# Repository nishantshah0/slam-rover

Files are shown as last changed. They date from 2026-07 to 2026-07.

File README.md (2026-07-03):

# SLAM Rover — Open-Source Design Package

A complete, buildable design for a budget (~$400 CAD) SLAM-capable autonomous rover: 3D-printed chassis CAD, simulation-tested Pico W firmware, wiring plans, risk analysis, and a staged bill of materials. Published as a reference design — everything needed to build one lives in this repo.

**What's here and how far it's been validated:**
- **Firmware** (MicroPython, Pico W): motor control, PIO quadrature encoders, WiFi/USB command protocol with fail-safe watchdog — validated 9/9 in a [host-side simulation harness](pico/host_test/run_sim.py)
- **CAD**: parametric chassis system — plate, motor clamps, and tolerance test coupon (Onshape); wheels, caster spacer, and body shell (OpenSCAD, sources included) — structural parts printed and dry-fitted on a Bambu P1S
- **Engineering docs**: [decision log](docs/decisions.md) (D1–D9), [risk register](docs/risks.md) (R1–R10), [staged BOM](docs/shopping-list.md), [build roadmap](docs/roadmap.md), [debugging log](docs/debugging-log.md)
- Hardware bring-up (motors/lidar/SLAM on the physical robot) is designed and documented but not yet executed — the [phase 1 guide](docs/phase1-guide.md) is the runbook for whoever does it first

## Gallery

| | | |
|---|---|---|
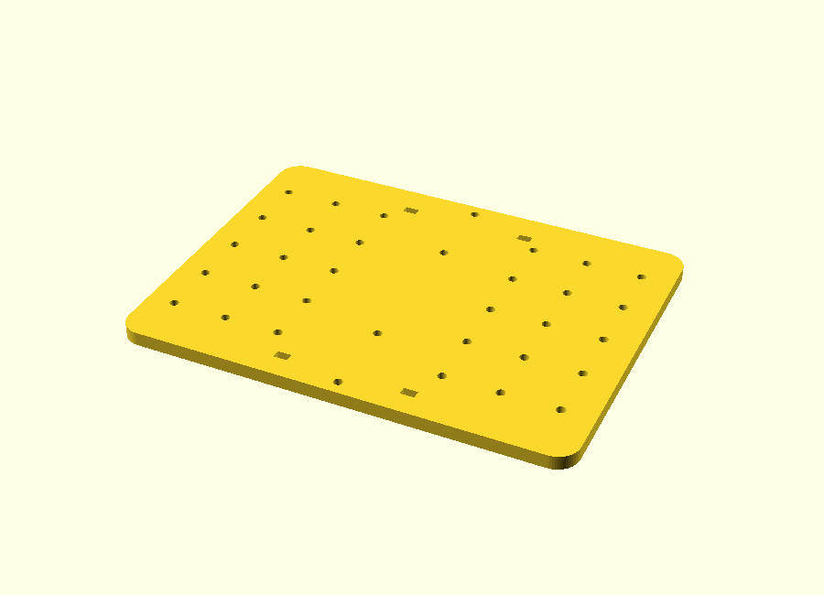
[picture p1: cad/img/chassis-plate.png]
chassis plate
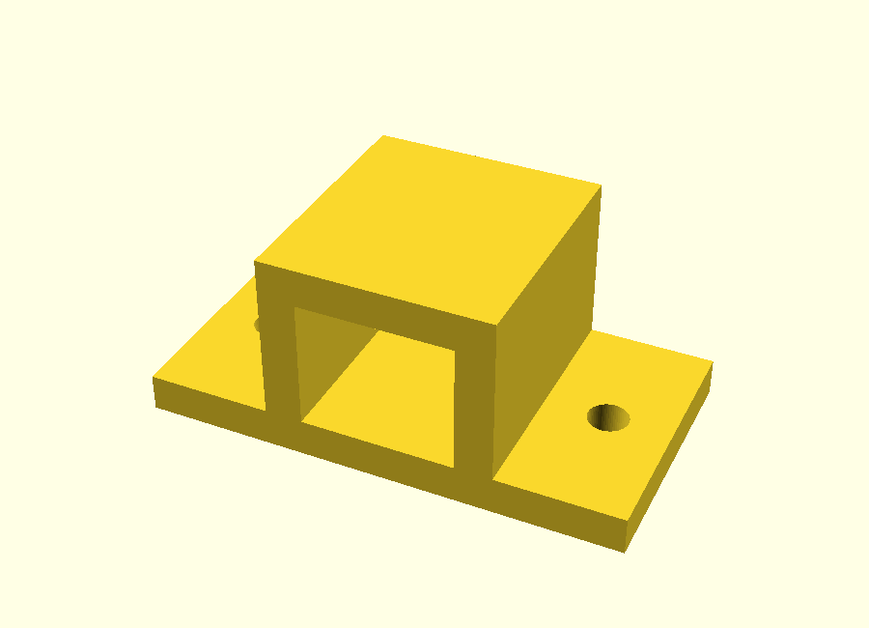
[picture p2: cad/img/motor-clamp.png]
motor clamp
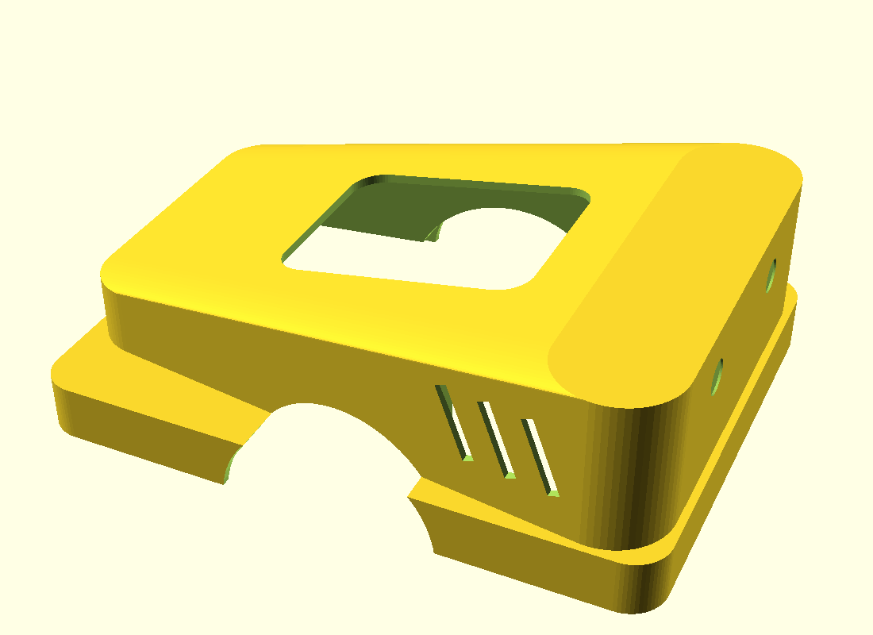
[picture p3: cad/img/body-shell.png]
body shell
|  |  |  |
| Chassis plate (34-hole grid system) | Motor clamp (N20, no-fastener tunnel) | Body shell (printable car-body skin) |
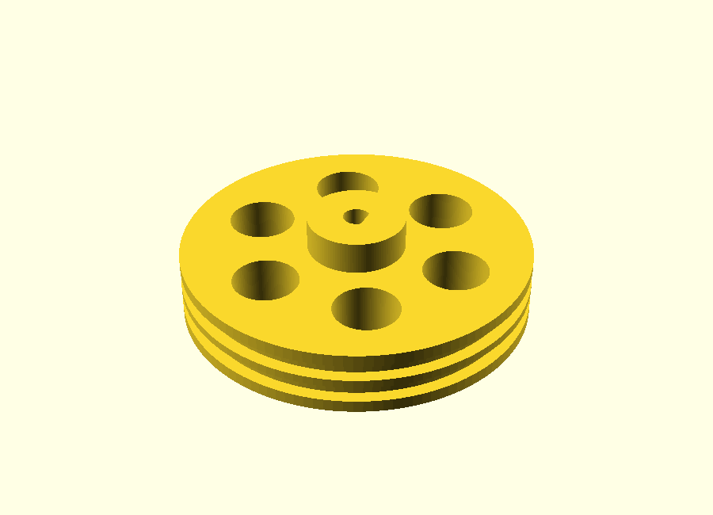
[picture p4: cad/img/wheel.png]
wheel
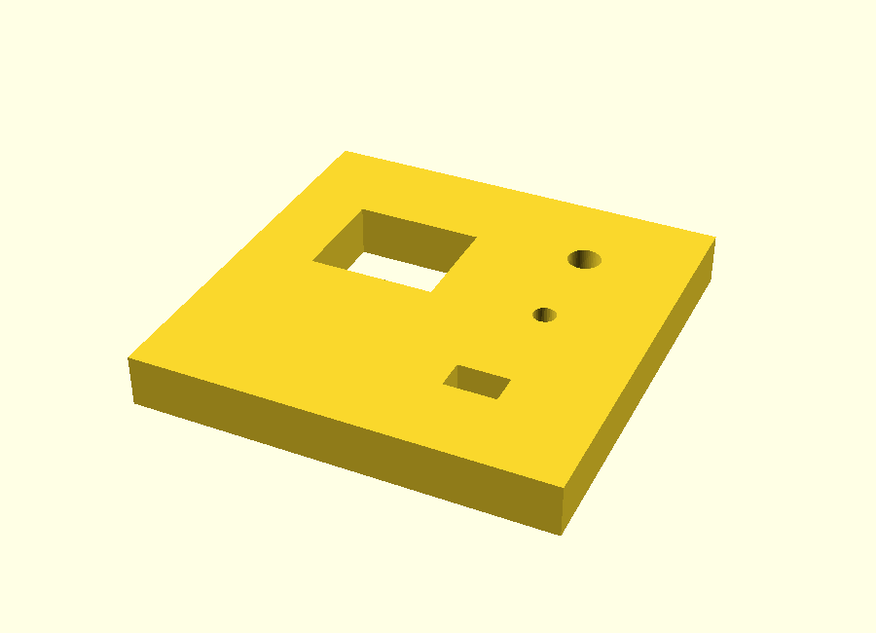
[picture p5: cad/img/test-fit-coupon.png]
test coupon
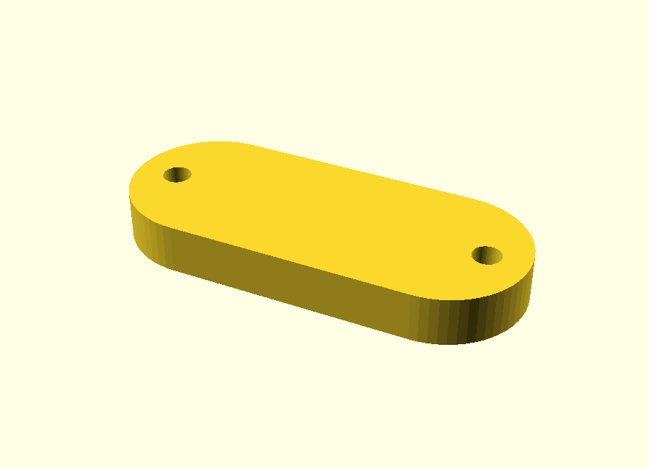
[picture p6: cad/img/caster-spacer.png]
caster spacer
|  |  |  |
| Drive wheel (rubber-band tires, D-bore) | Tolerance test coupon | Parametric caster spacer |

## Hardware

| Component | Choice | Rationale | Status |
|---|---|---|---|
| Compute | Raspberry Pi 5 | Runs ROS2 + SLAM | Decided |
| Real-time motor control | Raspberry Pi Pico | PWM + **encoder counting** (PIO) | Decided |
| Sensing | RPLidar A1 | Direct `LaserScan` fit for slam_toolbox ([D2](docs/decisions.md)) | Proposed |
| Chassis | **3D-printed diff-drive plate + caster** (Bambu P1S) | Skid-steer corrupts odometry; printing saves $ and adds CAD to portfolio ([D5](docs/decisions.md)) | Proposed |
| Motors | **N20 gearmotors with quadrature encoders** | SLAM needs odometry — encoders are not optional ([R1](docs/risks.md)) | Proposed |
| Motor driver | TB6612FNG or Cytron MDD3A (**not L298N**) | L298N wastes 2–4 V as heat ([D6](docs/decisions.md)) | Proposed |
| Power | Battery → motor rail + separate 5V/5A buck → Pi | Shared rail = brownout reboots ([D7](docs/decisions.md)) | Proposed |

3D printing (Bambu P1S) covers all *structure*: chassis plate, motor mounts, wheel hubs, lidar mast, Pi/Pico tray. Drivetrain internals (motors, gears, caster) stay off-the-shelf. Budget: **~$340–425 CAD total, bought in three stages of ~$90–165** ([shopping-list.md](docs/shopping-list.md)).

## Software Stack

- **ROS2 Jazzy** on Ubuntu 24.04 — *not Humble*: Humble's Ubuntu 22.04 doesn't support the Pi 5 ([D1](docs/decisions.md))
- **slam_toolbox** for SLAM
- **Nav2** for autonomous navigation (stretch goal)
- **Python** for ROS2 nodes; **MicroPython + PIO** on the Pico ([D4](docs/decisions.md))
- Dev environment: WSL2 (learning) + headless Pi + Foxglove Studio (live viz) ([D8](docs/decisions.md))

## Phased Build Plan (~6–8 weeks)

### Phase 0 (Week 0) — Order parts & set up dev environment
Shipping eats calendar time — order **Stage 1** of the [shopping list](docs/shopping-list.md) now (later stages get bought as earlier ones succeed). Meanwhile, all $0: WSL2 + Ubuntu 24.04 + ROS2 Jazzy on the Windows machine; chassis CAD in Onshape; firmware drafted in the Wokwi simulator; GitHub repo created ([D9](docs/decisions.md)). The Pi gets flashed when the Stage 2 box arrives (~week 2).

### Phase 1 (Weeks 1–2) — Get it moving
Assemble chassis, wire motor driver + Pico + two-rail power. Pico firmware: PWM drive, **encoder counting via PIO**, serial protocol, **command watchdog (fail-safe stop, [R4](docs/risks.md))**. Keyboard teleop over SSH. **No ROS2 yet** — isolate hardware learning from software learning.

### Phase 2 (Weeks 3–4) — ROS2 fundamentals + sensing + odometry
Two parallel tracks:
- **Learning track (WSL2, no robot):** nodes, topics, pub/sub, launch files, tf basics.
- **Robot track (Pi):** lidar publishing `LaserScan`; serial-bridge node (`cmd_vel` → Pico, encoder counts → Pi); **odometry node** publishing `odom` + the `odom → base_link` transform. Doing odometry here keeps Phase 3 from overloading.

### Phase 3 (Weeks 5–6) — SLAM integration
slam_toolbox + tf tree (`map → odom → base_link → laser`). Debug coordinate frames, lidar mounting/orientation ([R8](docs/risks.md)), drift; tune. Drive the room, save a clean map.

**✅ Success checkpoint: a rover that maps a room cleanly is a strong standalone demo, even if Phase 4 isn't reached.**

### Phase 4 (Stretch) — Autonomy
Nav2 for point-to-point autonomous navigation. Prep item: closed-loop wheel velocity control (PID on the Pico) makes Nav2 behave much better than open-loop PWM.

## Repo Layout

```
docs/
  roadmap.md         # Beginner roadmap: milestone ladders, concepts, definitions of done
  phase1-guide.md    # Full Phase 1 execution plan: wiring, firmware steps, pin map
  shopping-list.md   # Staged cart (~$340–425 CAD total, 3 purchases)
  debugging-log.md   # Running log: what broke, why, how it was fixed
  decisions.md       # Design decisions D1–D9 with rationale
  risks.md           # Known failure modes R1–R10 and mitigations
pico/                # Pico firmware: main.py + encoder.py + concept walkthrough (WRITTEN — verify at bring-up)
teleop/              # PC-side WASD driving script (WiFi/UDP or USB serial)
cad/                 # Chassis design spec for Onshape (plate, clamps, test-fit coupon)
ros2_ws/             # ROS2 workspace (Phase 2+)
```

**Start here:** [docs/roadmap.md](docs/roadmap.md) — the phase-by-phase ladder — and [docs/shopping-list.md](docs/shopping-list.md) for what to order.

## Debugging Log

Every non-trivial problem gets an entry in [docs/debugging-log.md](docs/debugging-log.md) — symptom, root cause, fix. This doubles as interview storytelling material.

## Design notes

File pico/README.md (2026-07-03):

# Pico Firmware — What Every Piece Is and Why

Three files, one job: turn "M 60 60" arriving over USB or WiFi into spinning
wheels, report back how far they actually turned, and fail safe.

| File | Role |
|---|---|
| [main.py](main.py) | Motors, watchdog, command parsing, WiFi/UDP, telemetry |
| [encoder.py](encoder.py) | PIO-hardware pulse counting (odometry's raw material) |
| [../teleop/teleop_wasd.py](../teleop/teleop_wasd.py) | Runs on your PC — the driver's seat |

## The concepts, in the order the code uses them

**PWM (Motor class).** A GPIO pin is only ever fully ON or OFF. So to get
"60% power," we switch it 20,000 times a second and make it ON 60% of each
cycle. The motor's inertia averages that into smooth partial power. 20 kHz is
chosen because it's above human hearing — at lower frequencies motors audibly
whine. The `DUTY_CAP = 0.85` exists because our 7.2 V battery feeds 6 V
motors: capping duty at 85% means the *average* voltage never exceeds spec.

**Sign-magnitude drive (why two pins per motor).** Inside the MDD3A is an
H-bridge — four electronic switches around the motor. PWM into the A input
closes one diagonal pair (current flows left-to-right: forward); PWM into B
closes the other diagonal (right-to-left: reverse). Our `Motor.set(-100..100)`
just decides which pin gets the duty cycle.

**Quadrature counting (encoder.py).** Two sensors watch a magnet disc on the
motor shaft, producing square waves offset by a quarter turn. Which signal
*leads* tells direction; counting *changes* tells distance. At speed that's
thousands of changes per second — too fast for Python — so a PIO state machine
(a tiny hardware co-processor inside the RP2040) does it and Python just asks
for the total. The PIO program is a MicroPython port of Raspberry Pi's own
reference implementation (credited in the file).

**The watchdog (main loop).** The firmware tracks when the last valid command
arrived. 400 ms of silence → motors stop, LED starts blinking. The teleop
script therefore *re-sends* the current command 10×/second even when nothing
changed — those repeats are a heartbeat, and silence means the driver is gone
(crashed script, dead cable, out of WiFi range). The rover never runs away.

**Two transports, one protocol.** Commands are plain text lines ("M 60 60")
whether they arrive by USB serial or WiFi UDP. Plain text costs a few bytes
but you can *type commands by hand* in Thonny to test — debuggability beats
efficiency everywhere in this project.

## Running it in Wokwi (now, $0, no hardware)

1. Go to **wokwi.com → "MicroPython on Pi Pico W"** new project.
2. Replace its main.py with ours; add a new file tab named `encoder.py` and
   paste ours in. (Encoder init may fail in the sim — that's expected and
   handled; you'll see the note and counts of 0.)
3. Set `WIFI_SSID = "Wokwi-GUEST"` (no password) to exercise the WiFi path,
   or leave `""` for serial-only.
4. Click ▶. In the serial monitor type `M 60 60` → watch telemetry flow.
   Click the Pico's pins panel or wire LEDs (long leg to GP2–GP5, short leg
   via a resistor to GND) to *see* the motor outputs light up.
5. **Watchdog test in sim:** send one `M 60 60`, then stop typing — within
   half a second: `# watchdog: no command for 400ms - motors stopped`.

The sim's one limit: your PC's teleop script can't reach into Wokwi's
virtual network, so the WASD-over-UDP experience waits for real hardware.
The *logic* it exercises is identical.

## Flashing the real Pico (when Stage 1 arrives)

1. Hold BOOTSEL, plug in USB → drag the MicroPython **Pico W** .uf2
   (micropython.org) onto the drive that appears.
2. In Thonny: save `encoder.py` and `main.py` onto the Pico (File → Save as →
   Raspberry Pi Pico). A file named `main.py` runs automatically at power-on.
3. Put your home WiFi into `WIFI_SSID`/`WIFI_PASSWORD` — the rover prints its
   IP at boot; that IP goes into the teleop `--udp` argument.
4. Bring-up order is phase1-guide Steps 1–4 — one subsystem at a time, wheels
   in the air.

## Tuning knobs you'll touch later

- `ENCODER_DIR` — flip signs after the Step 3 hand-spin test if a side counts
  backward.
- `DUTY_CAP` — raise toward 1.0 only if you switch to a true 6 V supply.
- `WATCHDOG_MS` — 400 is right for WiFi driving; don't raise it to "fix" a
  flaky link (fix the link).

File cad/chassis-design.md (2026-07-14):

# Chassis Design Spec — What Gets Modeled in Onshape

Modeled from scratch, no downloaded parts (that's the point — "designed the
chassis in CAD" is the interview line). This doc is the *engineering spec*:
dimensions, layout logic, and the print plan.

⚠️ All part dimensions marked **nominal** are typical for these components but
vary by listing — final-check them with calipers/ruler when parts arrive.
That's what the test-fit coupon is for.

## Component envelopes (nominal)

| Part | Size (mm) | Notes |
|---|---|---|
| N20 motor body | 12 × 10 × ~24 (+ encoder board ~11 behind) | 3 mm D-shaft, centered on the 12×10 face |
| Wheel | Ø34 × 7 | → axle center sits **17 mm** above ground |
| Ball caster | Ø12 ball, housing ~16 tall | usually 2× M3 mounting holes |
| MDD3A | ~37 × 31 | 4× M3 corner holes |
| Pico W | 51 × 21 | 4× M2.1 holes (M2 screws or zip tie) |
| Buck converter | ~45 × 22 | often M3 holes; else zip-tie slots |
| 6×AA holder (with switch) | ~58 × 48 × 29 | heaviest part — placement matters most |
| Half-size breadboard | 82 × 55 | has adhesive back |

## The layout logic (this reasoning is portfolio material)

- **Plate:** 160 × 120 × 5 mm, flat, printed face-down — fits the P1S bed
  with huge margin, no supports.
- **Wheels on the center line** (mid-length, one each side, outside the plate
  footprint so the plate needs no cutouts). Why center: the robot then spins
  about its own middle — cleaner odometry math and, later, the lidar sits
  directly over the rotation center, which SLAM likes.
- **Battery holder centered between the wheels, directly on the plate.** The
  heaviest mass over the axle = traction on the drive wheels and a stable
  spin. Put it anywhere else and the rover wheelies or the caster carries too
  much weight.
- **Caster at the rear center**, ~50 mm from the back edge.
- **Height math** (do this once, reuse forever): wheel center is 17 mm up;
  motor body is 10 mm tall with a centered shaft, and it hangs in a clamp
  whose 3 mm flange sits between motor and plate → plate underside sits at
  17 + 5 + 3 = **25 mm above ground** → the caster stack (housing + printed
  spacer) must also total **25 mm**, so the plate rides level. The spacer is
  a 5-minute print you'll iterate — expect one reprint after ground truth.
- **Electronics topside:** breadboard front-center (stick-on), MDD3A beside
  it, Pico on the breadboard itself, buck at the rear near the battery leads.
  Keep encoder (signal) wiring away from motor (power) wiring — parallel runs
  of the two invite electrical noise in the counts.

## Parts to model (in order)

**1. Test-fit coupon (print FIRST, before the real plate).** A 40 × 40 × 5 mm
tile containing: one motor-clamp pocket, one M3 hole, one M2 hole, one zip-tie
slot (3 × 5 mm). Print, test the real parts in it when they arrive, adjust
tolerances, *then* print the plate. Costs 10 minutes of filament; saves a
full plate reprint.

**2. Motor clamps (×2, identical — the design is symmetric, no mirroring
needed).** DESIGNED (SR-002, Session 2): a 38.3 × 20 × 3 flange with two Ø3.2
screw holes (5 mm from each end), an 18.3 × 20 × 13.3 block fused on top, and
a **12.3 × 10.3** motor tunnel through it (3 mm walls and roof; tolerance
number tracks whatever the coupon proves). Motor slides in from either end;
friction + two M3 screws to the plate hold it. Print flange-down, no supports.

**3. The plate.** (Coordinates finalized in Session 3 — origin at back-left
corner, X 0→160 toward the front, Y 0→120 left-to-right. Clamp holes: all at
X=80; Y = 5, 33.3, 86.7, 115 — the 28.3 pitch comes from the clamp flange.
Spare grids: Ø3.2 at 20 mm pitch, rear block X 10–50 and front block X 110–150,
Y 20–100 both. Battery zone X ~55–105 kept bare.)
One sketch + one extrude + hole patterns:
- 160 × 120 rectangle, corners filleted R8
- Motor clamp screw holes at the wheel positions (from the clamp design)
- Caster M3 holes at rear center
- MDD3A + buck M3 hole patterns
- A loose grid of spare M3 holes down the middle (future mounts — lidar mast
  bolts here in Phase 2, zero redesign)
- 4–6 zip-tie slots (3 × 5 mm) along the wire routes
- Battery zone: keep it bare; velcro holds the holder (tool-free battery swaps)

**4. Caster spacer.** Cylinder/block to make the caster stack 22 mm. Measure
the real caster first.

## Onshape session plan (~2–3 hrs total)

1. Free **student account** at onshape.com/edu (browser, nothing to install).
2. Learn exactly four tools — Sketch, Extrude, Hole/circle, Fillet — that's
   90% of this design.
3. Model in this order: coupon → clamp → plate → spacer. Each is one sketch
   + one extrude.
4. Make key numbers **variables** (`#plate_len`, `#motor_pocket_w`…) so
   coupon-measured corrections update the plate automatically. This is the
   difference between CAD and drawing — and a great interview detail.
5. Export STL → slice (4 walls, 30% infill, PLA is fine) → print.

## Print queue

| When | What |
|---|---|
| Now ($0) | Test-fit coupon — ready for the day parts arrive |
| After coupon passes | Plate + 2 clamps + caster spacer (~6 hr print, overnight) |
| Phase 2 | Lidar mast (bolts to the spare-hole grid) |

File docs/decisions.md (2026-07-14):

# Design Decisions

Decisions with rationale. Update status as things get locked in.
Cross-reference: [risks.md](risks.md) explains the failure modes behind several of these.

## D1 — ROS2 distro: Jazzy, not Humble (proposed)

**Status:** Proposed, needs confirmation before OS install.

The original plan said ROS2 Humble, but Humble requires **Ubuntu 22.04**, and
Ubuntu 22.04 **does not support the Raspberry Pi 5** (Pi 5 needs 23.10+).

Options:
1. **ROS2 Jazzy on Ubuntu 24.04** ← going with this. Pi 5 officially supported,
   Jazzy is an LTS (supported to 2029), slam_toolbox and Nav2 both fully
   supported. Humble tutorials translate almost 1:1 (swap "humble"→"jazzy").
2. Humble in Docker on Raspberry Pi OS — works, but adds container complexity
   a beginner doesn't need.
3. Swap Pi 5 for Pi 4 — supports Humble natively, but weaker compute for SLAM.

## D2 — Primary sensor: RPLidar A1 (proposed)

**Status:** Proposed.

For 2D SLAM with slam_toolbox, a 2D lidar is the direct path: it publishes
`LaserScan` messages, exactly what slam_toolbox consumes. The RPLidar A1 has a
maintained ROS2 driver (`sllidar_ros2`) and is the cheapest option (~$100).

Depth cameras (OAK-D Lite, RealSense) make SLAM *harder* for a first build:
visual/RGB-D SLAM is a different, more complex pipeline. A camera can be
**added later** for perception demos without changing the SLAM stack.

## D3 — Pi ↔ Pico link: plain USB serial (proposed)

**Status:** Proposed.

The Pico talks to the Pi over USB serial with a simple text protocol
(e.g. Pi→Pico `V <left_pwm> <right_pwm>`, Pico→Pi `E <left_count> <right_count>`
at a fixed rate). micro-ROS on the Pico is the "fancy" option but adds
significant setup complexity; a plain serial bridge node on the Pi achieves the
same thing and is far easier to debug. Can migrate to micro-ROS later as a
stretch refinement.

**Firmware requirement (see risk R4):** command watchdog — if no valid command
arrives for ~300–500 ms, stop the motors. The Pi side re-sends commands at
~10 Hz.

## D4 — Pico firmware language: MicroPython + PIO (proposed)

**Status:** Proposed; escalation path defined.

MicroPython keeps the whole project in one language and is much faster to
iterate on. The known weakness — missing encoder pulses at speed (risk R7) —
is solved by counting pulses with the Pico's **PIO hardware state machines**,
which MicroPython can program. If PIO-from-MicroPython becomes a fight, the
defined fallback is rewriting the firmware in the C SDK (which is *also* good
resume material — frame it as a deliberate engineering escalation, not a failure).

## D5 — Chassis: 3D-printed diff-drive plate + N20 encoder motors (revised)

**Status:** Revised 2026-07-01 — printed chassis replaces the bought kit.

Two constraints drove the original "buy a kit" call and both still hold
(risks R1, R2):

1. **Encoders are effectively required.** slam_toolbox expects odometry;
   without it maps smear. → **N20 gearmotors with quadrature hall encoders**
   (~$30/pair, come as plug-in modules, no soldering).
2. **Skid-steer lies to the encoders.** 4WD/tracked slips sideways in every
   turn, corrupting rotation odometry. → **2-wheel differential drive +
   caster** (the TurtleBot shape).

What changed: I have a **Bambu Lab P1S**, so the chassis *plate*,
motor mounts, wheel hubs, and lidar mast are **printed, not bought** — saves
~$40 and adds CAD design work (Onshape, free for students) to the portfolio,
which mechatronics recruiters value as much as code. The original plan's
"don't print the drivetrain" rule survives: gears, motors, and bearings stay
off-the-shelf; we print the *structure* (flat plates and brackets — easy,
strong, low-risk prints).

Fallback if chassis design stalls Phase 1 by more than a few days: Pololu
Romi chassis kit + encoder pair (~$55 CAD) drops in with the same electronics.

## D6 — Motor driver: SparkFun TB6612FNG (with headers), not L298N (decided)

**Status:** Decided 2026-07-02 (was: TB6612 or Cytron MDD3A; MDD3A isn't sold
on Amazon.ca and RobotShop had it out of stock, so TB6612 it is).

The tutorial-favorite L298N drops 2–4 V as heat (old Darlington design) — 6 V
motors would see ~3.5 V and crawl (risk R5). The **SparkFun TB6612FNG "with
Headers"** version keeps the no-solder rule: it pushes into the breadboard.

Specs check: VM up to 15 V (our 7.2–8.4 V pack ✓), 1.2 A/channel continuous /
3.2 A peak (N20 stall ~0.5–1 A ✓, brief stalls covered by peak rating).

**Wiring trick that keeps the firmware unchanged:** the TB6612 normally wants
3 pins per motor (IN1, IN2, PWM). Instead, tie **STBY, PWMA, PWMB all to
3V3** (always-on), and PWM the IN pins directly — GP2/GP3 → AIN1/AIN2,
GP4/GP5 → BIN1/BIN2. That reproduces the MDD3A's sign-magnitude behavior
exactly, so `main.py` needs zero changes. VCC (logic) → 3V3, VM → battery +,
grounds common.

## D7 — Power architecture: two rails, one battery (proposed)

**Status:** Proposed.

Motor voltage sag reboots a shared-supply Pi (risk R3). Architecture:

```
Battery (6×AA NiMH, ~7.2 V) ──┬── motor driver ── motors
                  └── 5V/5A buck converter ── Pi 5 ── (USB) lidar
                        (common ground across everything)
```

The Pi 5 specifically wants 5V/**5A**; on a weaker feed it caps USB output
current, which the lidar (~0.5 A) needs. Battery chemistry: LiPo (light,
powerful, needs careful handling) vs protected 18650/NiMH (heavier, safer) —
either works; pick based on comfort with LiPo safety.

## D8 — Dev environment: WSL2 for learning, headless Pi + Foxglove for the rover (proposed)

**Status:** Proposed.

- **ROS2 learning (Phase 2):** Ubuntu 24.04 + ROS2 Jazzy in **WSL2** on the
  Windows machine. RViz works via WSLg. No robot needed for the fundamentals.
- **The rover's Pi:** Ubuntu **Server** 24.04, headless, SSH only. RViz on a
  Pi is sluggish; don't try.
- **Live visualization:** **Foxglove Studio** on Windows → `foxglove_bridge`
  on the Pi over WiFi. Avoids DDS discovery between WSL2 and the LAN, which is
  flaky through WSL2's NAT (risk R6).

## D9 — Code workflow: GitHub as single source of truth (proposed)

**Status:** Proposed.

Docs live here (Windows/OneDrive); ROS2 code runs on the Pi; firmware is
flashed from wherever. Rule: **push after editing, pull before editing** —
GitHub is the sync point, never OneDrive or SCP (risk R9). Name the GitHub
repo something portfolio-worthy (e.g. `slam-rover`).

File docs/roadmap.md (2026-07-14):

# Beginner Roadmap — How You'll Actually Do This

You don't need to already know robotics to finish this project. You need to
climb a ladder of small, testable wins in the right order. This document is
the ladder.

## The five working rules

1. **One new variable at a time.** Never change two things between tests. If
   you wire a new component AND change code, and it breaks, you can't know
   which did it. This single habit is most of what "debugging skill" is.
2. **Bench before robot.** Every component proves itself on the desk (motor
   spins in mid-air, lidar publishes on a desk) before it gets mounted.
   Integration is where bugs hide; make sure the pieces were innocent first.
3. **Small wins, always demonstrable.** Each milestone below is something you
   can *see working* in under a minute. If you're 3 hours into something with
   nothing demonstrable, back up to the last working state.
4. **Log every fight.** When something breaks for more than ~20 minutes, it
   earns an entry in [debugging-log.md](debugging-log.md). This is your
   interview material generating itself.
5. **~8–10 hours/week.** That's the pace the 6–8 week timeline assumes. A
   blocked evening is normal; a blocked week means ask for help (see
   "When you're stuck" below).

## Working pattern

For every new topic: **concept first, then code, then test, then log.**
Understand what a thing *is* and why it exists before writing any of it;
write code in small pieces that run immediately; every fix gets logged.
Keep asking "why" — for an internship interview, understanding *why* the
tf tree is shaped the way it is beats having a working rover I can't explain.

---

## Phase 0 (Week 0) — Order parts, build your workshop

**Goal:** parts in the mail, dev environment working, so Week 1 starts with zero setup friction.

**New concepts:** flashing an OS image, SSH (controlling a computer with no
screen over the network), WSL2 (a real Linux inside Windows), git push/pull.

**Milestone ladder:**
- [ ] Order **Stage 1** of the [shopping list](shopping-list.md) (~$165)
- [x] WSL2 + Ubuntu 24.04 installed on this PC *(2026-07-02)*
- [x] ROS2 Jazzy installed in WSL2; talker/listener test passed ← *first ROS2 moment: done* *(2026-07-02)*
- [x] GitHub repo created and pushed: https://github.com/nishantshah0/slam-rover *(2026-07-02)*
- [ ] (moves to ~week 2, when the Stage 2 box arrives) Pi flashed with Ubuntu Server 24.04, SSH from Windows works

**Definition of done:** Stage 1 is ordered and you've seen two ROS2 nodes talk to each other in WSL2.

**Likely first fight:** WiFi config on a headless Pi (no screen to type on).
The fix is cloud-init/`network-config` on the SD card — set it up before first boot.

---

## Phase 1 (Weeks 1–2) — Get it moving

**Goal:** drivable rover via keyboard over SSH. No ROS2 anywhere — this phase is electronics + firmware only, on purpose.

**New concepts:**
- *Voltage/current/ground*, and why every board must share a ground
- *PWM* — how you get "70% speed" out of a pin that can only be ON or OFF (switch it very fast)
- *H-bridge* — the circuit trick that lets a motor run backwards (what the MDD3A does)
- *Quadrature encoders* — two offset pulse streams; the offset tells you spin direction, the count tells you distance
- *Serial (UART over USB)* — the byte-pipe the Pi and Pico talk through

**Milestone ladder** (each one is minutes-to-an-hour of work, in order):
- [ ] Pico blinks its LED (MicroPython "hello world" — proves toolchain)
- [ ] Pico echoes what you type over USB serial (proves the byte-pipe)
- [ ] One motor spins **on the bench**, driver wired, wheel in mid-air
- [ ] Motor speed and direction controlled from code (PWM working)
- [ ] Encoder counts stream to the screen as you turn the wheel **by hand** — watch the count go up, spin it backwards, watch it go down ← *this is odometry being born*
- [ ] Both motors + both encoders working on the bench
- [ ] **Watchdog test: unplug the USB cable mid-drive → motors stop within half a second** (risk R4 — do not skip)
- [ ] Chassis assembled, two power rails wired (battery→driver, battery→buck→Pi)
- [ ] Drive it around the room with WASD keys over SSH 🎉 **(film this)**

**Definition of done:** the WASD drive video, and the watchdog test passing.

**Likely first fights:** motor spins the wrong way (swap its two wires — every
robotics person has done this); nothing works because grounds aren't common
(multimeter finds it in minutes); encoder counts *down* when driving forward
(sign flip in code).

---

## Phase 2 (Weeks 3–4) — ROS2 fundamentals + sensing + odometry

**Goal:** by the end, the rover speaks fluent ROS2: lidar scans and odometry
out, velocity commands in. Two parallel tracks so a blocked one never stalls the week.

### Track A — Learn ROS2 in WSL2 (no robot needed)

**New concepts:** *nodes* (small programs that each do one job), *topics*
(named channels they publish/subscribe on — a group chat for programs),
*messages* (typed contents, e.g. `LaserScan`, `Twist`, `Odometry`), *launch
files* (start ten nodes with one command), *tf* (the live family tree of
"where is everything relative to everything else").

- [ ] Official ROS2 Jazzy beginner tutorials: CLI tools, then turtlesim
- [ ] Write your own publisher + subscriber pair in Python
- [ ] Write a node that subscribes to turtlesim's pose and publishes commands back — a closed loop, the shape of all robotics software
- [ ] First launch file

### Track B — Robot plumbing (on the Pi)

- [ ] ROS2 Jazzy on the Pi; `sllidar_ros2` driver publishing `/scan` — **see your room as a live point ring in Foxglove Studio on Windows** ← *the single most motivating moment of the whole project*
- [ ] `serial_bridge` node: subscribes `/cmd_vel` (velocity commands) → serial to Pico; reads encoder counts ← Pico
- [ ] Drive the rover with `teleop_twist_keyboard` — same driving as Phase 1, but now it's ROS2 messages doing it
- [ ] `odometry` node: encoder ticks → wheel distances → *diff-drive kinematics* (one page of geometry: ticks in, position-and-heading out) → publish `/odom` + the `odom → base_link` transform
- [ ] **Odometry sanity check:** drive 1 m forward with a tape measure down — does `/odom` say ~1 m? Rotate in place 360° — does heading come back to ~start?

**Definition of done:** Foxglove shows the scan ring live, and the tape-measure odometry test passes within ~5%.

**Likely first fights:** lidar USB permissions on Ubuntu (udev rules); WSL2↔Pi
networking temptation (don't — Foxglove over the bridge, per D8); radians vs
degrees somewhere in the odometry math.

---

## Phase 3 (Weeks 5–6) — SLAM: the boss fight

**Goal:** drive the rover around a room; watch a clean map build; save it. This is the phase that *is* the portfolio piece.

**New concepts:** *coordinate frames & the tf tree* (`map → odom → base_link → laser`
— who publishes each arrow and why), *scan matching* (sliding the current lidar
scan over the map until it clicks into place), *loop closure* (recognizing
"I've been here before" and snapping accumulated drift out of the whole map),
*URDF/static transforms* (telling ROS the lidar sits 12 cm above and 3 cm
ahead of the robot's center).

**Milestone ladder:**
- [ ] Static transform `base_link → laser` published (measure the lidar's mounting offset with a ruler — yes, really)
- [ ] tf tree verified with `view_frames` — one connected tree, no orphans
- [ ] slam_toolbox launches; map appears in Foxglove and grows as you drive
- [ ] Slow lap of the room (slow = better scans = better map)
- [ ] Loop closure observed: drive back to the start and watch the map visibly *snap* tighter
- [ ] Map saved (`map_saver`); the PNG goes in the repo ← **this image is the money shot**
- [ ] Repeatability: map the same room twice; the maps should agree

**Definition of done:** a saved map a stranger could recognize the room from, plus a screen-recording of it building.

**Likely first fights (this phase is 50% debugging by design):** map builds
rotated/mirrored (lidar mounted backwards → fix the static transform, not the
hardware); "message filter dropping message" (timestamps/QoS mismatch — a rite
of passage; worth decoding line by line); map smears in the long hallway
(drive slower, tune scan-matching, check odometry quality from Phase 2).

**⛳ Success checkpoint reached.** Everything after this line is bonus.

---

## Phase 4 (Stretch) — Autonomy with Nav2

**Goal:** click a point in the map; the rover drives itself there, around obstacles.

**New concepts:** *localization* (using a finished map to answer "where am I" —
slam_toolbox has a localization mode), *costmaps* (the map inflated by "don't
drive this close to walls"), *planners* (global = route on the map; local =
steering around what the lidar sees right now), *PID control* (closing the
loop so "send 0.2 m/s" actually produces 0.2 m/s at the wheels — Pico-side
upgrade that makes Nav2 dramatically better behaved).

**Milestone ladder:** PID wheel-velocity control on the Pico → Nav2 bringup on
the saved map → rover localizes → first click-to-drive goal → obstacle placed
mid-route gets avoided **(film this too)**.

---

## When you're stuck

In order: (1) re-read the error message slowly — ROS2 errors usually *do* say
what's wrong; (2) reduce to the last working state and re-add one thing;
(3) write out the exact error text + what changed since it last worked;
(4) 30 minutes of genuine stuckness = stop, log it, move to the other track —
sleep fixes robots more often than seems reasonable.

## The portfolio payoff (collect as you go)

- **Phase 1:** WASD driving video + a wiring photo + watchdog fail-safe story
- **Phase 2:** Foxglove screenshot of the live scan ring + the odometry tape-measure test
- **Phase 3:** the saved map PNG + a timelapse of it building + your two best debugging-log war stories
- **Phase 4:** click-to-drive video with an obstacle dodge
- **Throughout:** [debugging-log.md](debugging-log.md) *is* the answer to "tell me about a hard problem you solved" — with dates proving it happened.

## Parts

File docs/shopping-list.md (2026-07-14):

# Shopping List — Staged Purchases (~$90–165 CAD at a time)

Rebuilt for reality: first project, no existing gear except a **Bambu Lab P1S
3D printer**, budget-sensitive. Two big changes from v1:

1. **You buy in three stages matched to the build phases** — never more than
   ~$165 CAD at once, and each stage only gets bought if the previous one
   succeeded. Total exposure at any moment stays low.
2. **The P1S replaces the store-bought chassis** (decision D5 updated). You
   print the chassis plate, motor mounts, lidar mast, and wheels — which cuts
   ~$40 *and* adds CAD design work to the portfolio (mechatronics internships
   care about CAD as much as code).

Prices in CAD, Amazon.ca unless noted. AliExpress halves some prices if you
can tolerate 2–4 week shipping — fine for Stage 3, risky for Stage 1.

---

## Stage 1 — Buy now (~$165): everything for Phase 1, a complete driving robot

| Item | Spec | ~CAD | Notes |
|---|---|---|---|
| Raspberry Pi **Pico WH** | WiFi + headers pre-soldered | $13 | The robot's brainstem. The "W" ($3 extra) buys **wireless WASD driving** in Phase 1 — no cable dragging behind the rover |
| 2× **N20 gearmotors with encoders** | 6 V, ~200–300 RPM, quadrature hall encoder | $30 | The non-negotiable item (risk R1). Sold as modules with cables pre-attached — **no soldering needed** |
| **SparkFun TB6612FNG "with Headers"** motor driver | dual 1.2 A, headers PRE-soldered | $20 | Swapped from MDD3A (not sold on Amazon.ca). Pushes into the breadboard; motor cable's dupont ends push onto its pins. Wiring note: tie STBY+PWMA+PWMB to 3V3 and the firmware works unchanged (D6) |
| 2× wheels for N20 shafts (3 mm D-shaft) | 34–43 mm | $8 | Or print hubs + rubber-band/O-ring tires on the P1S — $0 |
| Ball caster | ~12 mm | $5 | The third wheel |
| 6×AA battery holder + NiMH AAs + charger | ~7.2 V pack | $40 | Start with alkalines ($8) if needed; NiMH later |
| Jumper wires + mini breadboard | dupont M/M, M/F | $15 | Phase 1 prototyping |
| Multimeter | any $15–20 unit | $18 | The one tool that isn't optional |
| 5 V / **5 A** buck converter | **with screw terminals** | $12 | Moved here from Stage 2: powers the Pico for untethered WiFi driving; later becomes the Pi's battery rail (D7) |
| M3 screw + nut assortment kit | M3 × 8/10/12/16 mix | $10 | Bolts clamps to plate, caster to plate — the printed parts are useless without these |
| Zip ties, small (2.5 mm wide) | 100-pack | $5 | Wire management through the plate's slots |
| Chassis plate, motor mounts | — | **$0** | **Printed on the P1S** — designed in Phase 1, CAD portfolio material |

**Stage 1 total: ~$165.** Deliverable: a keyboard-drivable robot with
encoder odometry and fail-safe firmware. *This is a complete standalone
project* — if you build it and hate the process (you won't), you've risked
$165, not $600.

## Stage 2 — Buy ~week 2 (~$130): the ROS2 brain, for Phase 2

| Item | Spec | ~CAD | Notes |
|---|---|---|---|
| Raspberry Pi 5, **4 GB** | 4 GB is enough for slam_toolbox | $85 | Used Pi 4 (4 GB, ~$50 on FB Marketplace) also runs ROS2 Jazzy fine — saves $35 |
| microSD 64 GB A2 | SanDisk Extreme class | $15 | |
| USB-C PD charger 27 W+ | any decent brand | $20 | Bench power during software work |

**Stage 2 total: ~$120 (or ~$85 with a used Pi 4).** (Buck converter moved to Stage 1.)

## Stage 3 — Buy ~week 3–4 (~$90–140): the lidar, for Phases 2/3

One item, three price points — decide when you get here:

| Option | ~CAD | Trade-off |
|---|---|---|
| **LDROBOT LD19 / STL-19P** (or D500 kit) | ~$90–100 | Newer, smaller, solid ROS2 driver (`ldlidar`) — the budget pick |
| **Used RPLidar A1** (eBay/Marketplace) | ~$60–80 | Cheapest path to the gold-standard beginner lidar |
| **New RPLidar A1** | ~$140 | Most tutorials, most community help when stuck |

Lidar mast/mount: **printed on the P1S, $0.**

---

## Budget summary

| | CAD |
|---|---|
| Stage 1 (driving robot) | ~$165 |
| Stage 2 (ROS2 brain) | ~$85–120 |
| Stage 3 (lidar) | ~$90–140 |
| **Full SLAM rover, total** | **~$340–425, spread over ~4 weeks** |

For calibration: a TurtleBot 4 Lite — the commercial version of this exact
robot — is **~$1,600 CAD**. And unlike a bought robot, *building* it is the
thing internship interviews actually ask about.

## What the P1S contributes (all $0, all portfolio)

- Chassis plate + motor mounts (Phase 1 — designed in Onshape, free for students)
- Wheel hubs if you skip bought wheels
- Pi/Pico/driver mounting tray
- Lidar mast (Phase 2/3)
- Eventually: an enclosure that makes the demo photos look professional

## The no-solder guarantee 🔩

Every connection in this robot is a **plug, a screw terminal, or a breadboard
push-in**. The complete map:

| Connection | How it's made |
|---|---|
| Pico ↔ breadboard | Pico **H** = headers pre-soldered, pushes into breadboard |
| Motors → MDD3A driver | motor wires into MDD3A **screw terminals** (screwdriver) |
| Battery pack → MDD3A + buck | bare leads into **screw terminals** |
| Encoder wires → Pico | motor's included cable → breadboard/dupont **push-in** |
| MDD3A signal pins → Pico | **dupont jumper wires** (they just push on) |
| Buck converter → Pi 5 | screw terminals in, USB-C out |
| Lidar → Pi | **USB cable**, nothing else |
| Pi ↔ Pico | **USB cable** |

**Two buying details that keep this true:**
1. Choose an N20 encoder motor listing that says **"with cable"** — the
   encoder cable comes pre-attached (factory-soldered, not by you) with
   dupont-style ends.
2. Choose a buck converter **with screw terminals** (many are; some are
   solder-pad only — avoid those).

Soldering is a 20-minute skill you can pick up at the university makerspace
*whenever you feel like it, or never*. It is not a gate on this project.

## Other tools you do NOT need to buy

- Wire strippers/heat gun — makerspace, or scissors-and-care at this scale.
- Soldering iron — see above. Not used anywhere in this build.

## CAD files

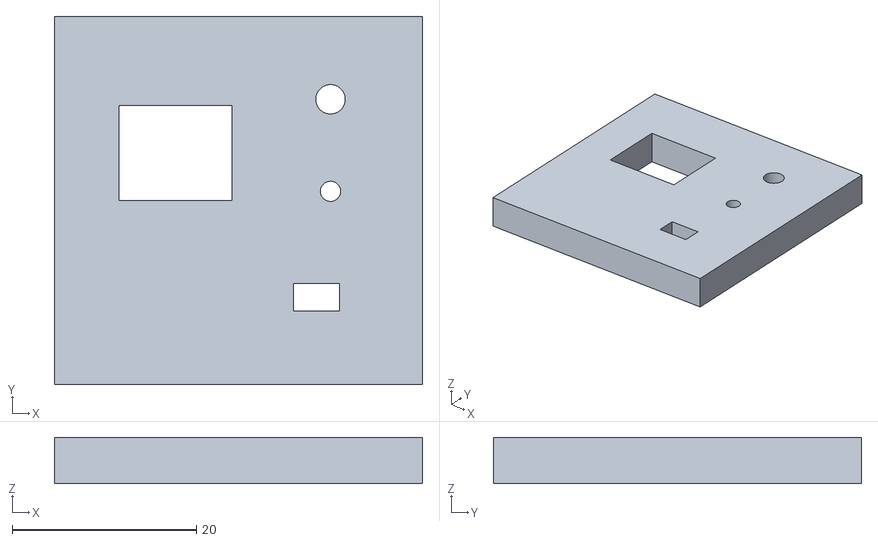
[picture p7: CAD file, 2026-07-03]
cad/test-fit-coupon.stl
40.0 x 40.0 x 5.00

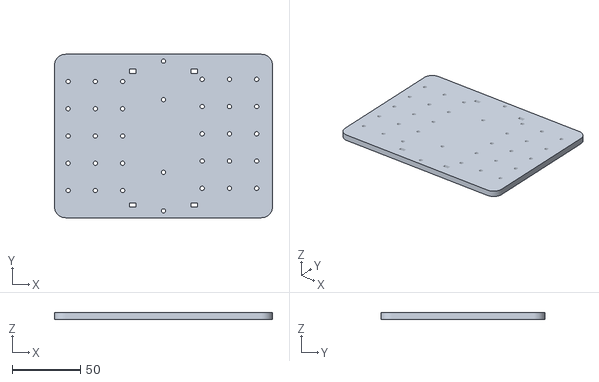
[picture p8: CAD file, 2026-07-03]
cad/chassis-plate.stl
160.0 x 120.0 x 5.00

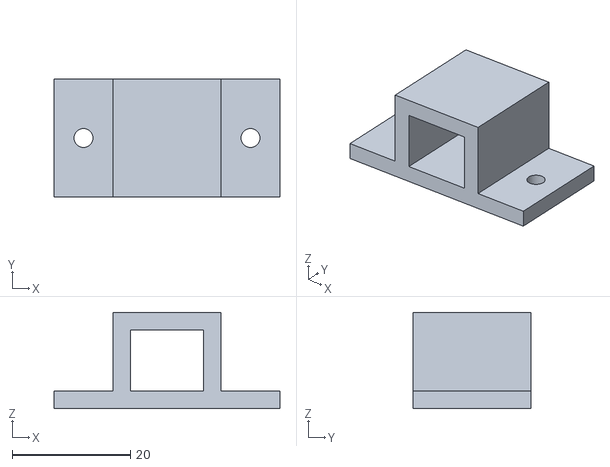
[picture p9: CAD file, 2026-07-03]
cad/motor-clamp.stl
38.3 x 20.0 x 16.3

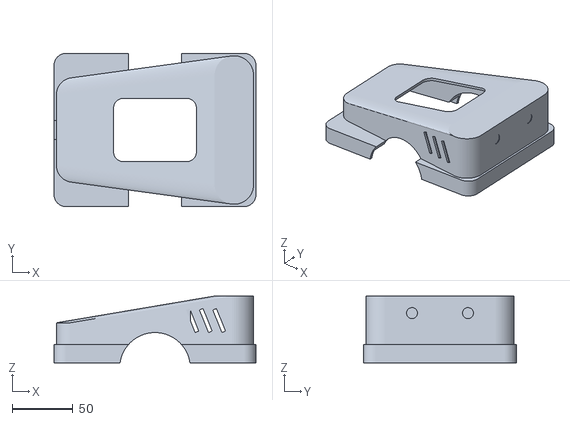
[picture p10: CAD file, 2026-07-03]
cad/body-shell.stl
166.0 x 126.0 x 55.0

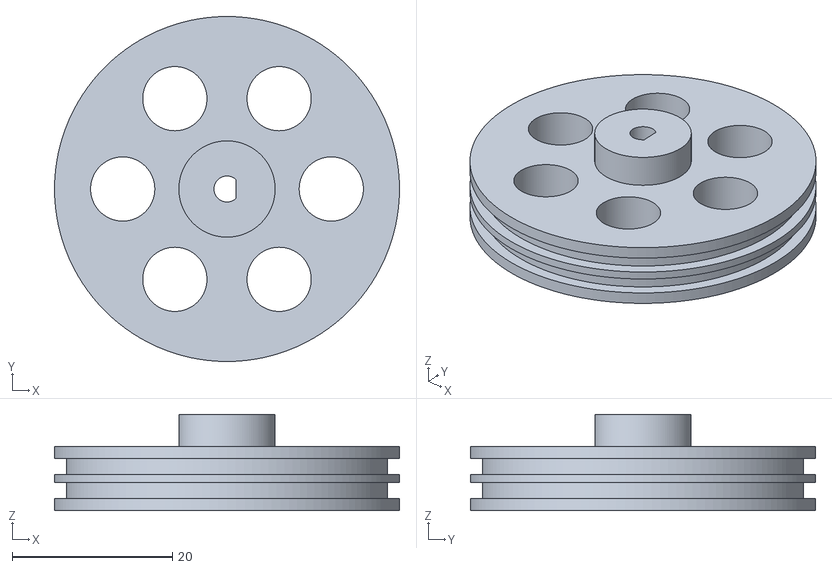
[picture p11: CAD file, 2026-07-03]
cad/wheel.stl
43.0 x 43.0 x 12.0

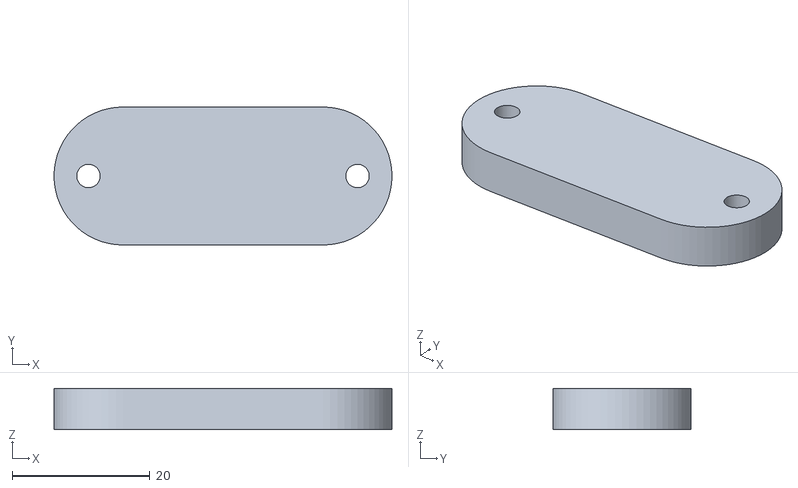
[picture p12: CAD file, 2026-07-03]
cad/caster-spacer.stl
49.0 x 20.0 x 6.00

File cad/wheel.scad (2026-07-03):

// ===== SLAM Rover — printed drive wheel (SR-004) =====
// Replaces the $8 bought wheels. Print 2: PLA, 4 walls, 30% infill,
// flat face down, no supports.
// TIRES: stretch two rubber bands into the rim grooves — bare PLA slips.

$fn = 120;                 // circle smoothness (segments)

// --- parameters -------------------------------------------------------------
wheel_d      = 43;         // overall diameter — matches the height math in
                           // cad/chassis-design.md (plate underside 29.5 mm)
wheel_w      = 8;          // rim width
hub_d        = 12;         // hub boss diameter
hub_extra    = 4;          // hub boss sticks out this far past the rim face
bore_d       = 3.25;       // N20 shaft is 3.0 round — +0.25 print compensation
flat_w       = 2.75;       // N20 "D" flat is 2.5 across — same compensation
                           // >>> tune bore_d & flat_w from coupon results —
                           // bore must be SNUG (wheel is friction-driven)
groove_depth = 1.5;        // rubber-band grooves in the rim
groove_w     = 2;
lighten_d    = 8;          // weight-saving holes in the web
lighten_r    = 13;         // circle they sit on

// --- the wheel ---------------------------------------------------------------
difference() {
    union() {
        cylinder(d = wheel_d, h = wheel_w);                  // rim/disc
        cylinder(d = hub_d, h = wheel_w + hub_extra);        // hub boss
    }
    // two rubber-band grooves around the rim
    for (z = [1.5, wheel_w - 1.5 - groove_w])
        translate([0, 0, z]) ring_cut(wheel_d, groove_depth, groove_w);
    // D-shaped shaft bore, all the way through
    translate([0, 0, -1])
        linear_extrude(wheel_w + hub_extra + 2) d_shaft_profile();
    // lightening holes
    for (a = [0 : 60 : 359])
        rotate([0, 0, a]) translate([lighten_r, 0, -1])
            cylinder(d = lighten_d, h = wheel_w + 2);
}

// ring-shaped channel cut into the outer rim
module ring_cut(od, depth, w) {
    difference() {
        cylinder(d = od + 2, h = w);
        translate([0, 0, -0.5]) cylinder(d = od - 2*depth, h = w + 1);
    }
}

// circle with one flat = the N20 "D" shaft cross-section
module d_shaft_profile() {
    difference() {
        circle(d = bore_d);
        translate([flat_w - bore_d/2, -bore_d/2 - 1])
            square(bore_d + 2);
    }
}

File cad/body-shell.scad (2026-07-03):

// ===== SLAM Rover — body shell (SR-006) "make it not a brick" =====
// A car-body style skin that slides down over the printed chassis plate and
// grips its edges (friction lip — no fasteners). Wedge profile: low tail
// over the caster end, high cab over the electronics end.
//
// PRINT: upside-down (roof on the bed, slicer: flip 180 about X), PLA,
// 2-3 walls, 10% infill, no supports needed (walls flare <45deg).
// ~7-9 h, ~150 g. PRINT LAST — after the electronics are assembled and
// measured, in case the cab height needs a bump.
//
// Coordinates: X 0..SHELL_L (low X = tail/caster end), Y 0..SHELL_W,
// Z 0 = top surface of the chassis plate.

$fn = 64;

// --- key dimensions ----------------------------------------------------------
SHELL_L = 166;   SHELL_W = 126;          // outer footprint
PLATE_L = 160;   PLATE_W = 120;          // the printed plate underneath
WALL    = 2.4;   ROOF    = 2.4;
CAB_H   = 46;    // height over the electronics end (clears breadboard+wires)
TAIL_H  = 24;    // height over the caster end (clears battery: 29mm... at
                 // its X the roof is ~35 — see slope note below)
SKIRT   = 9;     // how far the shell wraps down past the plate top
CLEAR   = 0.5;   // per-side clearance around the plate (friction fit; tune)
OX = (SHELL_L - PLATE_L) / 2;            // plate offset inside shell (3,3)
OY = (SHELL_W - PLATE_W) / 2;

module blob(x, y, r, h) { translate([x, y, 0]) cylinder(r = r, h = h); }

// the wedge body: hull between tall cab corners and low tail corners.
// i = wall inset (0 = exterior, WALL = interior cavity)
module wedge(i, h_cab, h_tail) {
    hull() {
        blob(148 - i,  18 + i, 16, h_cab);   // cab corners (high X end)
        blob(148 - i, 108 - i, 16, h_cab);
        blob( 16 + i,  34 + i, 14, h_tail);  // tail corners (narrower nose)
        blob( 16 + i,  92 - i, 14, h_tail);
    }
}

// full-footprint skirt band that wraps the plate edge
module skirt_band(i, h) {
    hull()
        for (p = [[10,10],[SHELL_L-10,10],[10,SHELL_W-10],[SHELL_L-10,SHELL_W-10]])
            blob(p[0] + (p[0] < 50 ? i : -i), p[1] + (p[1] < 50 ? i : -i), 10, h);
}

difference() {
    // ---------------- solid body ----------------
    union() {
        wedge(0, CAB_H, TAIL_H);
        translate([0, 0, -SKIRT]) skirt_band(0, SKIRT + 6);  // bumper band
    }

    // ---------------- hollow it out ----------------
    // main cavity (walls WALL thick, roof ROOF thick)
    translate([0, 0, -SKIRT - 1])
        wedge(WALL, CAB_H - ROOF + SKIRT + 1, TAIL_H - ROOF + SKIRT + 1);
    // plate pocket: the shell slides over the plate like a lid
    translate([0, 0, -SKIRT - 1])
        hull()
            for (p = [[OX+8, OY+8], [OX+PLATE_L-8, OY+8],
                      [OX+8, OY+PLATE_W-8], [OX+PLATE_L-8, OY+PLATE_W-8]])
                blob(p[0], p[1], 8 + CLEAR, SKIRT + 1);

    // ---------------- wheel arches ----------------
    // wheels sit at plate mid-length (shell X=83), axle ~13 below plate top
    translate([83, -2, -13]) rotate([-90, 0, 0])
        cylinder(d = 58, h = SHELL_W + 4);

    // ---------------- top hatch (battery access / future lidar mast) -------
    translate([0, 0, TAIL_H])
        hull()
            for (p = [[83-26, 63-18], [83+26, 63-18], [83-26, 63+18], [83+26, 63+18]])
                blob(p[0], p[1], 8, CAB_H);

    // ---------------- rear-side vents (cab end, 3 per side) ----------------
    for (side = [0, 1], k = [0, 1, 2])
        translate([116 + k*11, side ? SHELL_W - 9 : -3, 16])
            rotate([0, -22, 0])
                cube([3.2, 12, 20]);

    // ---------------- headlight pockets (tall face, cosmetic) --------------
    for (y = [40, 86])
        translate([SHELL_L - 2.6, y, CAB_H - 14])
            rotate([0, 90, 0]) cylinder(d = 9, h = 4);

    // ---------------- cable/USB notch (tail wall) --------------------------
    translate([-2, 55, -2]) cube([10, 16, 12]);
}

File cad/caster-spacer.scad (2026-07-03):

// ===== SLAM Rover — caster spacer (SR-005) =====
// Makes the caster stack match the drive-wheel geometry so the plate sits
// level. Height budget (see cad/chassis-design.md):
//   plate underside = 21.5 (43mm wheel radius) + 5 (motor half-height)
//                     + 3 (clamp flange) = 29.5 mm above ground
//   spacer h = 29.5 − (measured caster height)
// >>> The default h is a PLACEHOLDER. Measure the real caster when it
//     arrives, set h, re-render, print. (This is why it's code.)

$fn = 60;

spacer_l     = 49;    // caster base plate length (Amazon listing spec)
spacer_w     = 20;
h            = 6;     // PLACEHOLDER — set to 29.5 − measured caster height
hole_spacing = 39;    // caster mounting hole spacing (listing spec)
hole_d       = 3.4;   // M3 screw or zip-tie clearance

difference() {
    // rounded-end bar
    hull()
        for (x = [-1, 1])
            translate([x * (spacer_l/2 - spacer_w/2), 0, 0])
                cylinder(d = spacer_w, h = h);
    // mounting holes, through
    for (x = [-1, 1])
        translate([x * hole_spacing/2, 0, -1])
            cylinder(d = hole_d, h = h + 2);
}

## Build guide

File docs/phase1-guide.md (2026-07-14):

# Phase 1 Guide — Get It Moving (Weeks 1–2)

The complete Stage 1 execution plan. End state: a wireless, keyboard-driven
robot with encoder feedback and fail-safe firmware, on a chassis you designed.
No ROS2 anywhere in this phase — that's deliberate (learn hardware without
learning ROS2 at the same time).

**Golden rules for the whole phase:**
- Wheels off the ground for every first test of anything.
- Never touch wiring while the battery is connected.
- Multimeter checks polarity *before* a board sees power, every time.
- Change one thing between tests. One.
- 20+ minute fight → entry in [debugging-log.md](debugging-log.md).

---

## Step 0 — Order + while-the-box-ships (Days 1–3)

**0.1 Order the Stage 1 cart** ([shopping-list.md](shopping-list.md), ~$165).
Get the 6×AA holder **with a built-in switch** — that's your power switch.

**0.2 Install Thonny** (thonny.org) — a beginner Python IDE that talks to the
Pico natively. This is your firmware cockpit for all of Phase 1.

**0.3 Chassis CAD.** Make a free student **Onshape** account
(runs in the browser, nothing to install). Design targets:

- **Plate:** ~160 × 120 mm, 4–5 mm thick. Fits the P1S bed easily.
- **Layout:** two N20s on the *center line* (left/right edges), caster at the
  rear, battery holder centered and low (heaviest part near the wheels =
  stable + honest odometry), breadboard + MDD3A + buck on top with room to spare.
- **Motor mounts:** N20s are a standard brick shape (~12×10×26 mm + gearbox);
  printed C-clamp mounts with M2 screw holes (or snap-fit) — proven pattern,
  one modeling session.
- **Print settings:** PLA is fine, 4 walls, 30% infill, no supports needed —
  everything is designed flat-side-down.

Design time budget: 2–3 hours across a couple of evenings. **This is CAD
portfolio material — export nice screenshots as you go.**

**0.4 (Optional, $0):** start Phase 0's software half — WSL2 + ROS2 Jazzy on
this PC. Independent of everything above.

---

## Step 1 — Pico hello world (Evening 1, ~1 hour)

**Concepts first:** what firmware is; what MicroPython is (Python that runs
*on* the chip, no OS); what the REPL is (a live Python prompt running on the
Pico — you type, the chip obeys instantly).

1. Hold the **BOOTSEL** button, plug the Pico into USB → it appears as a USB
   drive. Drag the MicroPython **.uf2** file onto it (Pico W version, from
   micropython.org). It reboots as a Python machine. That's "flashing."
2. Open Thonny → select the Pico interpreter → type into the REPL:
   blink the onboard LED.
3. Save a `main.py` that blinks forever → unplug/replug → it blinks with no
   PC attached. **The Pico is now autonomous.**

✅ **Done when:** LED blinks with no computer attached.

---

## Step 2 — One motor spins on the bench (Evening 2, ~2 hours)

**Concepts first:** voltage/current/ground; why every board must share a
ground (electricity needs a complete loop and a common "zero" reference);
**PWM** — the pin can only be fully ON or OFF, so we switch it thousands of
times per second and the *ratio* of on-time becomes "70% power"; **H-bridge**
— the four-switch circuit inside the MDD3A that lets current flow through the
motor in either direction (that's reverse).

**Wiring (battery DISCONNECTED, wheels in the air):**

| From | To |
|---|---|
| Battery + / − | breadboard power rails (multimeter-check polarity FIRST) |
| TB6612 VM | battery + rail; TB6612 GND → battery − rail |
| TB6612 VCC, **STBY, PWMA, PWMB** | all → Pico 3V3 (the tie-high trick, D6) |
| Motor 1 M+/M− (dupont ends of its cable) | TB6612 AO1 / AO2 pins |
| TB6612 AIN1 / AIN2 | Pico GP2 / GP3 (dupont) |
| Pico GND | battery − rail ← **the common ground** |

The logic per motor (with PWMA/B tied high): PWM on IN1 → forward, PWM on
IN2 → reverse, both low → stop — identical to what the firmware expects.

**Code ladder (each ~10 lines, run from Thonny):** motor full speed → motor
at 30/60/90% duty (see PWM become "speed") → reverse → a `set_motor(speed)`
function taking −100…+100.

One battery note: 6×NiMH ≈ 7.2 V into 6 V motors — slight overvolt is fine;
we cap PWM duty at ~85% in code and never think about it again.

✅ **Done when:** `set_motor(50)` then `set_motor(-50)` does exactly what it
says, wheel in the air.
⚠️ **Predicted fight:** motor spins the wrong way → swap its two wires at the
screw terminals. Everyone does this. Log it anyway.

---

## Step 3 — Encoders: odometry is born (Evening 3, ~2 hours)

**Concepts first:** the encoder is two tiny sensors watching a magnet disc on
the motor shaft, producing two pulse streams (A and B) offset by a quarter
cycle — **quadrature**. Count edges = distance; whether A leads B or B leads A
= direction. And **PIO**: the Pico's little hardware co-processors that count
these pulses in hardware so Python never misses one at speed (risk R7). The
PIO quadrature program lives in `pico/encoder.py` — worth reading line by line.

**Wiring per encoder:** VCC → Pico 3V3, GND → GND, A/B → GP6/GP7 (left).

**The magic test:** run the counter, **turn the wheel slowly by hand**, watch
the number climb. Backwards → it falls. You are watching odometry exist.

**Calibrate:** rotate the wheel exactly 10 turns by hand (mark the tire),
read the count, divide by 10 → **counts per wheel revolution**. Write this
number down — it's a constant in every odometry calculation for the rest of
the project.

✅ **Done when:** hand-spin counts up forward / down backward, and you know
your counts-per-rev number.

---

## Step 4 — Both sides + serial protocol + THE WATCHDOG (Evenings 4–5, ~3 hours)

Duplicate motor 2 (GP4/GP5) and encoder 2 (GP8/GP9). Then give the robot a language:

```
PC → Pico:   M <left> <right>      speeds −100…100, e.g. "M 60 60"
Pico → PC:   E <left_count> <right_count>    streamed at 20 Hz
```

Firmware structure (~60 lines): read a line → parse →
set motors → every 50 ms send encoder counts → **and a watchdog: if no valid
`M` command has arrived in 400 ms, stop both motors** (risk R4).

✅ **Done when — the watchdog test:** drive via typed commands, then just
*stop typing* → wheels halt within half a second. Later: kill the connection
mid-drive → same result. **Film this test** — "my firmware fails safe" is an
interview line.

---

## Step 5 — Assembly on your printed chassis (Weekend, ~3 hours)

Print the final plate + mounts (revised with anything the bench testing turned up).
Mount: motors in their printed clamps, wheels on shafts, caster, battery
holder (velcro or screws), breadboard + MDD3A + buck on standoffs or foam
tape. Wire it — same circuit as the bench, just tidier: power wires twisted,
signal wires zip-tied away from motor wires, nothing touching a wheel.

**Power for untethered driving:** battery → buck (screw terminals) → set the
buck to **exactly 5.0 V with the multimeter BEFORE connecting anything** →
buck output → Pico **VSYS + GND** pins. (Safe to also have USB plugged in;
the Pico handles both.)

✅ **Done when:** rover sits on its wheels, both motors respond, encoders
count, nothing rattles when you shake it gently.

---

## Step 6 — Wireless WASD driving (Evenings 6–7, ~3 hours)

Why the Pico **W**: it has WiFi, so teleop needs no cable and no extra parts.

1. Pico joins your home WiFi at boot (10 lines of MicroPython).
2. Pico listens for UDP packets carrying the same `M <l> <r>` commands.
   **The watchdog doesn't care whether commands arrive by USB or WiFi — walk
   out of range and the rover stops.** Same fail-safe, zero new safety code.
3. On the PC: a small Python script (`teleop/teleop_wasd.py`) — hold
   W/A/S/D → sends commands at 10 Hz; release → sends stop.

First drive: rover on the floor, slow speed cap, thumb hovering over the
battery switch. Then: **film the demo video.** Drive a lap, spin in place,
park it.

✅ **PHASE 1 DONE when:** WASD lap on video + watchdog kill-test on video.

⚠️ **Predicted fights:** university/dorm WiFi blocks device-to-device traffic
(use your phone's hotspot instead — works every time); one wheel slightly
faster than the other so it drives in a shallow arc (normal! open-loop motors
differ — *this is exactly why encoders and closed-loop control exist*, and
it foreshadows Phase 2).

---

## Pin map (single source of truth)

| Pico pin | Goes to |
|---|---|
| GP2 / GP3 | MDD3A motor **left** (A = forward, B = reverse) |
| GP4 / GP5 | MDD3A motor **right** |
| GP6 / GP7 | Encoder **left** A / B |
| GP8 / GP9 | Encoder **right** A / B |
| 3V3 (pin 36) | Both encoders VCC |
| GND (any) | Common ground: MDD3A GND pin + encoder GNDs + buck − |
| VSYS (pin 39) | Buck + output (5.0 V, verified by multimeter first) |

## Phase 1 exit checklist

- [ ] WASD driving video (wireless)
- [ ] Watchdog kill-test video
- [ ] Counts-per-wheel-rev number written down
- [ ] Wiring photo + CAD screenshots saved
- [ ] `pico/` firmware pushed to GitHub
- [ ] At least 2 debugging-log entries (there will be more)
- [ ] You can explain to a rubber duck: PWM, H-bridge, quadrature, watchdog

Then Stage 2 order goes in, and Phase 2 begins.

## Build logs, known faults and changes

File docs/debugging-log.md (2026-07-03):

# Debugging Log

Running record of every non-trivial problem: what broke, why, and how it was fixed.
Written for two audiences — future-me debugging something similar, and interview stories ("tell me about a hard bug you solved").

## Entry template

```markdown
## YYYY-MM-DD — Short title of the problem

**Phase:** 1/2/3/4
**Symptom:** What you observed (error message, wrong behavior, nothing happening).
**Expected:** What should have happened.
**Investigation:** What you checked, in order. Dead ends count — they show process.
**Root cause:** The actual underlying problem.
**Fix:** What resolved it.
**Lesson:** One-liner takeaway.
```

---

<!-- Entries go below, newest first -->

## 2026-07-02 — "5 + #clamp_pitch" rejected in a dimension box

**Phase:** 1 (chassis plate CAD)
**Symptom:** Typing `5 + #clamp_pitch` into an Onshape dimension errored, even though `#clamp_pitch` alone worked fine.
**Root cause:** Unit strictness. A bare `5` in an expression is a unitless number; `#clamp_pitch` is a length (28.3 mm). Onshape refuses to add a number to a length — the same class of unit-mismatch error that killed the Mars Climate Orbiter.
**Fix:** `5mm + #clamp_pitch` — give every literal its units when mixing with variables.
**Lesson:** In engineering tools, units are part of the value, not decoration. Strictness that feels pedantic is protecting you.

## 2026-07-02 — Sketch linear pattern refused to go vertical

**Phase:** 1 (chassis plate CAD)
**Symptom:** Second direction of a *sketch* linear pattern kept duplicating holes horizontally no matter what was clicked.
**Fix / better tool:** Abandoned the sketch pattern; cut ONE hole, then used the *feature-level* Linear pattern, where directions are chosen by clicking actual plate edges (bottom edge = direction 1, left edge = direction 2) — unambiguous by construction.
**Lesson:** When a tool makes you guess (drag arrows, hidden angles), look for the variant that lets you point at real geometry instead. Feature patterns > sketch patterns for patterning cuts.

## 2026-07-02 — Motor pocket came out the wrong size in first CAD sketch

**Phase:** 1 (chassis CAD, test-fit coupon)
**Symptom:** Pocket in the Onshape sketch measured ~9.2 × 7 mm instead of the required 12.3 × 10.3 mm, despite "everything being dimensioned."
**Expected:** A 12.3 × 10.3 pocket, fully defined.
**Investigation:** All four dimensions were distances from the tile's edges to the pocket's edges (7, 20, 13, 23.792). The 23.792 with random decimals was the tell — that gap was just wherever the mouse happened to drop the rectangle, and the pocket's size became "whatever was left over."
**Root cause:** Over-dimensioned *position* (gaps from every edge) instead of dimensioning *size + position*. The feature's actual design intent — "this pocket is 12.3 wide because the motor is 12 wide" — wasn't captured anywhere in the sketch.
**Fix:** Deleted the top/right gap dimensions; dimensioned the pocket's own edges (12.3, 10.3) plus two position dims (7 from left, 20 from bottom). Sketch went fully defined (black) with the correct size.
**Lesson:** Dimension what you *mean*: a feature's size directly, then its position — never let a dimension be implied by leftovers. Blue lines = under-defined = something can still drift; weird decimals = a value nobody chose.

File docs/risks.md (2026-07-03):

# Risk Register — Where This Build Can Fail

Every item here is a *known* failure mode of this exact kind of build (Pi + Pico
+ lidar + ROS2 SLAM rover), with the why and the mitigation. Ordered by severity.

---

## R1 — No wheel encoders → SLAM produces a smeared, useless map 🔴 CRITICAL

**The problem:** The original hardware list has no encoders. slam_toolbox
expects **odometry** — a running estimate of "how far have I moved" — published
as an `odom → base_link` transform. It fuses that with lidar scan-matching.
Without odometry, scan-matching alone has to guess the robot's motion from
scratch every scan; in feature-poor areas (long hallways, blank walls) it loses
lock and the map smears or folds over itself.

**Why encoders solve it:** Encoders are small sensors on the motor shafts that
count wheel rotations. Wheel rotations × wheel circumference = distance moved.
That's odometry. The Pico counts encoder pulses (this is *the* reason a
real-time microcontroller is in the design) and streams counts to the Pi.

**Mitigation:**
- Buy motors **with quadrature hall encoders** (e.g. N20 or JGA25-371 gearmotors
  with encoders). Do NOT buy the cheap yellow "TT motor" kits — no usable encoders.
- Encoder reading is now part of Phase 1 firmware; the odometry node is Phase 2.

## R2 — Skid-steer (4WD/tracked) has bad rotation odometry 🔴 HIGH

**The problem:** A 4-wheel or tracked chassis turns by *skidding* — the wheels
slip sideways during every turn. Slipping wheels lie: encoders say "we turned
90°" but the robot actually turned 70°. Rotation error is the most damaging
kind for SLAM (a small heading error becomes a large position error a few
meters later).

**Mitigation:** Use a **2-wheel differential drive chassis + caster wheel**.
Two driven wheels turn without skidding, so encoder odometry is honest. This is
what TurtleBots use — it's the standard indoor SLAM platform shape for a
reason. If you must use 4WD, expect to lean much harder on scan-matching and
tune for it. See decision D6.

## R3 — Power brownouts reboot the Pi mid-run 🔴 HIGH

**The problem:** The Pi 5 wants **5V/5A (25W)** — more than most USB power
banks or cheap converters deliver. Worse, if motors and Pi share one supply,
every motor start/stall pulls the battery voltage down for a few milliseconds
("voltage sag"), and the Pi browns out and reboots. This shows up as
"my rover randomly restarts when it drives" — a classic.

**Mitigation — two separate power rails from one battery:**
- Battery (6×AA NiMH pack) → **motor driver directly** (motors tolerate sag)
- Battery → **dedicated 5V/5A buck converter → Pi 5** (buck rides through sag)
- **Common ground between everything** (circuits need a shared voltage reference)
- The lidar (~0.5A) powers off the Pi's USB — fine *if* the Pi itself has a 5A
  feed (on a weaker feed the Pi limits total USB output current).

## R4 — Runaway rover: motors keep spinning when software dies 🟠 MEDIUM

**The problem:** The Pico holds the last motor command it received. If the
serial link drops, the Pi crashes, or a node hangs, the rover keeps driving
into the wall at full speed.

**Mitigation:** A **watchdog timeout in the Pico firmware**: if no valid
command arrives for ~300–500 ms, stop the motors. The Pi-side teleop/driver
node therefore re-sends commands at ~10 Hz even when unchanged. This is
non-negotiable and is now a Phase 1 firmware requirement. (It's also a great
interview line: "my firmware fails safe.")

## R5 — Wrong motor driver: the L298N trap 🟠 MEDIUM

**The problem:** Nearly every beginner tutorial uses the L298N. It's ancient
Darlington-transistor tech that *eats 2–4 V* of your battery as heat — your
6 V motors might see 3.5 V and crawl.

**Mitigation:** Use a modern MOSFET driver: **TB6612FNG** (cheap, ~1 A/channel)
or a **Cytron MDD3A/MDD10A** (more headroom, dead simple). Near-zero voltage
drop, no heatsink drama.

## R6 — No dev-machine plan: RViz on the Pi is painful 🟠 MEDIUM

**The problem:** RViz (ROS2's 3D visualization tool — you'll live in it during
Phase 3) is sluggish on a Pi, and the plan had ROS2 learning happening…where?
The rover has no screen.

**Mitigation:**
- Run the Pi **headless** (Ubuntu Server 24.04, SSH in).
- Learn ROS2 in **WSL2 on this Windows machine** (Ubuntu 24.04 + ROS2 Jazzy
  installs cleanly; RViz works via WSLg). All Phase 2 ROS2 exercises happen
  here — no robot required.
- To visualize the *live rover*, use **Foxglove Studio** on Windows connected
  to a `foxglove_bridge` on the Pi over WiFi. This deliberately sidesteps DDS
  discovery between WSL2 and the LAN, which is flaky through WSL2's NAT — a
  rabbit hole not worth entering.

## R7 — MicroPython misses encoder pulses at speed 🟡 LOW-MED

**The problem:** A geared motor's encoder can emit thousands of pulses/second.
Counting them with Python interrupt handlers drops counts at speed → odometry
silently under-reports distance.

**Mitigation:** Use the Pico's **PIO** (Programmable I/O — tiny hardware
state machines that count pulses with zero CPU involvement). Usable from
MicroPython. If it becomes a fight, that's the trigger to switch to the C SDK
(decision D4).

## R8 — Lidar mounting and orientation surprises 🟡 LOW-MED

**The problem:** Three recurring ones: (a) the lidar is mounted low and sees
the rover's own posts/wires as permanent obstacles; (b) its "forward" doesn't
match the robot's forward, so the map builds rotated/mirrored; (c) motor
vibration blurs scans.

**Mitigation:** Mount it **top-center with 360° clearance** (this is your one
3D-printed mount); establish the `base_link → laser` transform carefully in
Phase 3 (this is exactly what tf is for); add foam/rubber standoffs if scans
look noisy. Also: RPLidar struggles with direct sunlight and matte-black
surfaces — demo indoors, curtains drawn.

## R9 — Two-computer code workflow confusion 🟡 LOW

**The problem:** This repo lives in OneDrive on Windows, but the ROS2 code
*runs* on the Pi (Linux). Editing in both places without discipline = lost work.

**Mitigation:** **GitHub is the single source of truth.** Push from wherever
you edit, pull before you edit anywhere else. (Also: create the GitHub repo
with a portfolio-worthy name like `slam-rover` — recruiters see repo names.)

## R10 — Slow-burn practical risks 🟡 LOW

- **Parts lead time:** shipping can eat 1–2 weeks of an 8-week plan → order
  each stage *early* (Stage 1 in Week 0; Stage 2 by ~week 2; Stage 3 by ~week 3),
  and prefer fast shipping over AliExpress for anything on the critical path.
  If a part dies, that's when the university makerspace / a quick Amazon
  next-day order covers you — the lean cart skips pre-bought spares.
- **SD card corruption:** cutting power without shutdown corrupts the card
  eventually → `sudo shutdown now` before flipping the switch; keep a backup
  image of the card once it's set up.
- **Battery safety:** LiPos are unforgiving (charge on a LiPo-safe surface,
  never over-discharge). A protected 18650 pack or NiMH pack is the
  lower-stress option at slight weight/power cost.

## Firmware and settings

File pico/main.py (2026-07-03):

# SLAM Rover — Phase 1 firmware (Raspberry Pi Pico W, MicroPython)
#
# What this does, in one breath: listens for motor commands over USB serial
# AND WiFi (UDP), drives two motors through the MDD3A, streams encoder counts
# back 20 times a second, and — most importantly — STOPS THE MOTORS if no
# command has arrived for 400 ms (the watchdog, risk R4).
#
# Command protocol (both transports, plain text lines):
#   in :  "M <left> <right>"   speeds -100..100      e.g.  M 60 60
#   out:  "E <left_count> <right_count>"             every 50 ms
#
# Concepts explained in pico/README.md. Wiring in docs/phase1-guide.md pin map.

import sys
import time
import select
from machine import Pin, PWM

# ------------------------------- CONFIG -------------------------------------
PIN_LEFT_FWD, PIN_LEFT_REV = 2, 3      # MDD3A M1A, M1B
PIN_RIGHT_FWD, PIN_RIGHT_REV = 4, 5    # MDD3A M2A, M2B
PIN_ENC_LEFT = 6                       # left encoder A=GP6, B=GP7
PIN_ENC_RIGHT = 8                      # right encoder A=GP8, B=GP9

DUTY_CAP = 0.85          # 7.2 V pack into 6 V motors -> never exceed 85% duty
PWM_FREQ = 20_000        # 20 kHz: above human hearing, motors don't whine
WATCHDOG_MS = 400        # silence longer than this => motors stop
TELEMETRY_MS = 50        # encoder report interval (20 Hz)

WIFI_SSID = ""           # "" = skip WiFi (USB-only). Wokwi sim: "Wokwi-GUEST"
WIFI_PASSWORD = ""       # Wokwi-GUEST has no password
UDP_PORT = 8888

ENCODER_DIR = (1, 1)     # flip to -1 per side if counts run backward (Step 3)

# ------------------------------- MOTORS -------------------------------------
# The MDD3A speaks "sign-magnitude": PWM on the A pin drives forward, PWM on
# the B pin drives reverse, both idle = coast/stop. So each motor is just two
# PWM outputs and a rule about which one gets the duty cycle.

class Motor:
    def __init__(self, pin_fwd, pin_rev):
        self.fwd = PWM(Pin(pin_fwd)); self.fwd.freq(PWM_FREQ)
        self.rev = PWM(Pin(pin_rev)); self.rev.freq(PWM_FREQ)
        self.set(0)

    def set(self, speed):  # speed: -100 .. +100
        speed = max(-100, min(100, speed))
        duty = int(abs(speed) / 100 * DUTY_CAP * 65535)
        if speed >= 0:
            self.rev.duty_u16(0)
            self.fwd.duty_u16(duty)
        else:
            self.fwd.duty_u16(0)
            self.rev.duty_u16(duty)


left_motor = Motor(PIN_LEFT_FWD, PIN_LEFT_REV)
right_motor = Motor(PIN_RIGHT_FWD, PIN_RIGHT_REV)

def stop_all():
    left_motor.set(0)
    right_motor.set(0)

# ------------------------------ ENCODERS ------------------------------------
# Wrapped in try/except so the firmware still runs on simulators that lack
# PIO support — encoders then read 0 and everything else works.
try:
    from encoder import QuadratureEncoder
    enc_left = QuadratureEncoder(PIN_ENC_LEFT)
    enc_right = QuadratureEncoder(PIN_ENC_RIGHT)
    def read_encoders():
        return (ENCODER_DIR[0] * enc_left.read(),
                ENCODER_DIR[1] * enc_right.read())
except Exception as e:
    print("# encoder init failed (ok in simulation):", e)
    def read_encoders():
        return (0, 0)

# ------------------------------- WIFI / UDP ---------------------------------
udp_sock = None
udp_client = None  # whoever talked to us last gets the telemetry

if WIFI_SSID:
    try:
        import network, socket
        wlan = network.WLAN(network.STA_IF)
        wlan.active(True)
        wlan.connect(WIFI_SSID, WIFI_PASSWORD)
        deadline = time.ticks_add(time.ticks_ms(), 15_000)
        while not wlan.isconnected() and time.ticks_diff(deadline, time.ticks_ms()) > 0:
            time.sleep_ms(200)
        if wlan.isconnected():
            ip = wlan.ifconfig()[0]
            print("# WiFi up:", ip, "UDP port", UDP_PORT)
            udp_sock = socket.socket(socket.AF_INET, socket.SOCK_DGRAM)
            udp_sock.bind(("0.0.0.0", UDP_PORT))
            udp_sock.setblocking(False)
        else:
            print("# WiFi connect timed out - USB serial only")
    except Exception as e:
        print("# WiFi failed:", e, "- USB serial only")

# ------------------------------ COMMAND INPUT -------------------------------
poller = select.poll()
poller.register(sys.stdin, select.POLLIN)
serial_buf = ""

def poll_serial_line():
    """Non-blocking: returns one complete line from USB serial, or None."""
    global serial_buf
    while poller.poll(0):
        ch = sys.stdin.read(1)
        if ch in ("\n", "\r"):
            line, serial_buf = serial_buf, ""
            if line:
                return line
        else:
            serial_buf += ch
    return None

def poll_udp_line():
    """Non-blocking: returns one command line from WiFi, or None."""
    global udp_client
    if udp_sock is None:
        return None
    try:
        data, addr = udp_sock.recvfrom(64)
        udp_client = addr
        return data.decode().strip()
    except OSError:      # nothing waiting
        return None

def handle_command(line):
    """Parse 'M <left> <right>'. Returns True if it was a valid command."""
    parts = line.split()
    if len(parts) == 3 and parts[0] == "M":
        try:
            left_motor.set(int(parts[1]))
            right_motor.set(int(parts[2]))
            return True
        except ValueError:
            pass
    return False

# ------------------------------- MAIN LOOP ----------------------------------
led = Pin("LED", Pin.OUT)
last_cmd_ms = time.ticks_ms() - WATCHDOG_MS   # start "expired": motors off
last_telemetry_ms = time.ticks_ms()
watchdog_tripped = True
stop_all()
print("# rover firmware ready")

while True:
    now = time.ticks_ms()

    for line in (poll_serial_line(), poll_udp_line()):
        if line and handle_command(line):
            last_cmd_ms = now
            watchdog_tripped = False

    # THE WATCHDOG: commands stopped arriving -> stop moving. This is what
    # makes a dropped WiFi link or a crashed PC script safe.
    if not watchdog_tripped and time.ticks_diff(now, last_cmd_ms) > WATCHDOG_MS:
        stop_all()
        watchdog_tripped = True
        print("# watchdog: no command for %dms - motors stopped" % WATCHDOG_MS)

    if time.ticks_diff(now, last_telemetry_ms) >= TELEMETRY_MS:
        last_telemetry_ms = now
        l, r = read_encoders()
        msg = "E %d %d" % (l, r)
        print(msg)
        if udp_sock is not None and udp_client is not None:
            try:
                udp_sock.sendto(msg.encode(), udp_client)
            except OSError:
                pass

    # LED tells you the rover's state at a glance:
    # solid = driving on fresh commands, slow blink = idle/watchdog-stopped
    led.value(1 if not watchdog_tripped else (now // 500) % 2)

    time.sleep_ms(5)

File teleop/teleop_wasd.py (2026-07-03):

"""SLAM Rover — Phase 1 teleop. Hold WASD to drive, release to stop.

Two ways to connect (matching the firmware's two transports):

    python teleop_wasd.py --udp 192.168.1.42        # WiFi (rover prints its IP at boot)
    python teleop_wasd.py --serial COM5             # USB cable (find port in Device Manager)

Keys: W/S forward/back, A/D turn, SPACE instant stop, +/- speed, ESC quit.

Needs: pip install pygame        (and: pip install pyserial   for --serial)

SAFETY DESIGN NOTE: this script sends a command 10× per second even when
nothing changed. That's not waste — it's the firmware watchdog's heartbeat.
Close this window, unplug the cable, or walk out of WiFi range, and the
rover stops itself within 400 ms because the heartbeat vanished.
"""

import argparse
import sys

SEND_HZ = 10
DEFAULT_SPEED = 50   # % — start gentle; raise with '+' once trusted


def make_sender(args):
    if args.udp:
        import socket
        sock = socket.socket(socket.AF_INET, socket.SOCK_DGRAM)
        dest = (args.udp, args.port)
        print(f"UDP -> {dest[0]}:{dest[1]}")
        return lambda line: sock.sendto(line.encode(), dest)
    else:
        import serial  # pyserial
        ser = serial.Serial(args.serial, 115200, timeout=0)
        print(f"Serial -> {args.serial}")
        return lambda line: ser.write((line + "\n").encode())


def main():
    ap = argparse.ArgumentParser(description="WASD teleop for the rover")
    group = ap.add_mutually_exclusive_group(required=True)
    group.add_argument("--udp", metavar="ROVER_IP", help="drive over WiFi")
    group.add_argument("--serial", metavar="COM_PORT", help="drive over USB")
    ap.add_argument("--port", type=int, default=8888, help="UDP port (default 8888)")
    args = ap.parse_args()

    send = make_sender(args)

    import pygame
    pygame.init()
    screen = pygame.display.set_mode((420, 160))
    pygame.display.set_caption("Rover teleop - WASD drives, SPACE stops, ESC quits")
    font = pygame.font.SysFont("consolas", 18)
    clock = pygame.time.Clock()

    speed = DEFAULT_SPEED
    running = True
    while running:
        for event in pygame.event.get():
            if event.type == pygame.QUIT:
                running = False
            elif event.type == pygame.KEYDOWN:
                if event.key == pygame.K_ESCAPE:
                    running = False
                elif event.key in (pygame.K_PLUS, pygame.K_EQUALS):
                    speed = min(100, speed + 10)
                elif event.key == pygame.K_MINUS:
                    speed = max(10, speed - 10)

        keys = pygame.key.get_pressed()
        drive = (keys[pygame.K_w] - keys[pygame.K_s]) * speed
        turn = (keys[pygame.K_d] - keys[pygame.K_a]) * speed
        if keys[pygame.K_SPACE]:
            drive = turn = 0

        # differential-drive mixing: turning = wheels at different speeds
        left = max(-100, min(100, drive + turn))
        right = max(-100, min(100, drive - turn))
        send(f"M {left} {right}")

        screen.fill((20, 20, 30))
        for i, text in enumerate([
            f"speed {speed}%   (+/- to change)",
            f"sending: M {left} {right}",
            "release keys = stop | close window = watchdog stops rover",
        ]):
            screen.blit(font.render(text, True, (200, 220, 200)), (12, 12 + 26 * i))
        pygame.display.flip()

        clock.tick(SEND_HZ)  # the 10 Hz heartbeat

    send("M 0 0")
    pygame.quit()


if __name__ == "__main__":
    sys.exit(main())

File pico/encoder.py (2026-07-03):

# Quadrature encoder counter using the Pico's PIO hardware.
#
# WHY THIS EXISTS (risk R7): the N20 encoders emit thousands of pulses/second
# at speed. Counting them in Python interrupts silently drops counts. The PIO
# is a tiny hardware state machine inside the RP2040 that watches the two
# encoder pins every clock cycle and keeps the count in a register — Python
# just asks for the total when it wants it.
#
# HOW QUADRATURE WORKS: the encoder outputs two square waves, A and B, offset
# by a quarter cycle. Each time the pin pair changes state, the 2-bit
# (old A,B) + 2-bit (new A,B) pattern tells the PIO whether the wheel moved
# +1 or -1 step. The 16-entry jump table below encodes exactly that: the
# program computes a 4-bit index (old state << 2 | new state) and jumps into
# the table, which routes to increment / decrement / no-change.
#
# PROVENANCE: MicroPython port of Raspberry Pi's official pico-examples
# quadrature_encoder.pio, as posted (and reported working) on the Raspberry Pi
# forums (viewtopic.php?t=378082, user BillTodd, Oct 2024).
# NOTE: verify on real hardware at bring-up (hand-spin test, phase1-guide
# Step 3) — this file cannot be fully tested in simulation.

import rp2
from machine import Pin


@rp2.asm_pio(autopush=False, autopull=False)
def _quadrature_counter():
    # --- 16-entry jump table (must sit at PIO address 0) -------------------
    # index = (previous A,B state << 2) | (current A,B state)
    jmp("update")        # 00 -> 00  no movement
    jmp("decrement")     # 00 -> 01
    jmp("increment")     # 00 -> 10
    jmp("update")        # 00 -> 11  invalid transition (skipped a state)

    jmp("increment")     # 01 -> 00
    jmp("update")        # 01 -> 01
    jmp("update")        # 01 -> 10  invalid
    jmp("decrement")     # 01 -> 11

    jmp("decrement")     # 10 -> 00
    jmp("update")        # 10 -> 01  invalid
    jmp("update")        # 10 -> 10
    jmp("increment")     # 10 -> 11

    jmp("update")        # 11 -> 00  invalid
    jmp("increment")     # 11 -> 01
    label("decrement")   # 11 -> 10  (doubles as the decrement handler)
    jmp(y_dec, "update")     # y holds the count; jmp y-- decrements it
    label("update")      # 11 -> 11

    # --- main loop ----------------------------------------------------------
    wrap_target()
    set(x, 0)
    pull(noblock)            # did Python request the count? (put() anything)
    mov(x, osr)              # x = request flag (0 if TX FIFO was empty)
    mov(osr, isr)            # stash previous pin state in OSR
    jmp(not_x, "sample_pins")
    mov(isr, y)              # requested: hand the count (y) to Python
    push()
    label("sample_pins")
    mov(isr, null)
    in_(osr, 2)              # shift in previous pin state (2 bits)
    in_(pins, 2)             # shift in current pin state (2 bits)
    mov(pc, isr)             # jump into the table at that 4-bit index
    label("increment")
    mov(x, invert(y))        # y+1 done as ~(~y - 1): PIO can only decrement
    jmp(x_dec, "increment2")
    label("increment2")
    mov(y, invert(x))
    wrap()
    nop()
    nop()
    nop()


class QuadratureEncoder:
    """One encoder on two consecutive pins (A = base_pin, B = base_pin + 1)."""

    _next_sm = 0  # state machine IDs 0..3 handed out in order

    def __init__(self, base_pin):
        Pin(base_pin, Pin.IN, Pin.PULL_UP)
        Pin(base_pin + 1, Pin.IN, Pin.PULL_UP)
        self.sm = rp2.StateMachine(
            QuadratureEncoder._next_sm,
            _quadrature_counter,
            freq=125_000_000,
            in_base=Pin(base_pin),
        )
        QuadratureEncoder._next_sm += 1
        self.sm.active(1)

    def read(self):
        """Current signed count. Forward = one sign, backward = the other
        (which is which depends on wiring — establish it in the hand-spin
        test and flip ENCODER_DIR in main.py if needed)."""
        self.sm.put(1)               # request
        raw = self.sm.get()          # reply
        if raw & 0x8000_0000:        # sign-extend 32-bit two's complement
            raw -= 0x1_0000_0000
        return raw

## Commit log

2026-07-03 Project foundation: docs, Pico firmware, teleop, CAD specs
    - Full build plan, staged shopping list, risk register, decisions D1-D9
    - Phase 1 Pico WH firmware (PWM drive, PIO quadrature encoders, serial+UDP
    protocol, 400ms fail-safe watchdog) with host simulation harness (9/9)
    - WASD teleop client (WiFi/UDP or USB serial)
    - Chassis CAD specs; coupon, motor clamp and plate designed and printed
    - Debugging log with first three entries
    [encoder.py, main.py, teleop_wasd.py]
2026-07-03 Pre-order check: add M3 hardware + zip ties, sync budget totals
    Stage 1 is now ~$165 (screws and zip ties were missing); full build
    ~$340-425 CAD. Verified MDD3A (4-16V, 1.8-12V logic, 20kHz PWM, 3A/ch)
    and N20 encoder specs against datasheets before ordering.
2026-07-03 Swap motor driver to SparkFun TB6612FNG (Amazon.ca availability)
    MDD3A is not sold on Amazon.ca. TB6612 with pre-soldered headers keeps
    the no-solder rule; STBY+PWMA+PWMB tied to 3V3 preserves the firmware
    sign-magnitude interface unchanged. Wiring table updated.
2026-07-03 Add code-CAD parts: printed drive wheels + parametric caster spacer
    OpenSCAD sources with rendered STLs. Wheels (43mm, rubber-band tires,
    D-bore with print compensation) replace the bought wheels; spacer height
    is a parameter to set after measuring the real caster.
    [caster-spacer.scad, caster-spacer.stl, wheel.scad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]
2026-07-03 Add body shell (SR-006): car-body skin over the chassis plate
    OpenSCAD + STL + render preview. Wedge profile with wheel arches, side
    vents, bumper skirt that friction-grips the plate edge, and a top hatch
    centered on the rotation center (battery access now, lidar mast pass-
    through later). Print last, after electronics are assembled.
    [body-shell.scad, body-shell.stl]
2026-07-03 Publish as design package: Onshape STLs, render gallery, README reframe
    Adds the three Onshape-designed STLs (coupon, clamp, plate), preview
    renders for all six printed parts, and repositions the README as an
    open-source reference design with validation status stated per artifact.
    [chassis-plate.stl, motor-clamp.stl, test-fit-coupon.stl]
2026-07-14 Tighten docs wording in roadmap, guides, and decisions
2026-10-17 Drop shelved framing; add infrastructure use-case directions
2026-10-17 Pick leak hunting as the infrastructure use case; add Phase 5
2026-10-17 README: lead with Plumb, add progress checklist, cut repeated caveats
2026-10-17 Add a fallback for every part; mark printed chassis parts as done
2026-10-17 README: electronics wired; on-hardware testing is next
